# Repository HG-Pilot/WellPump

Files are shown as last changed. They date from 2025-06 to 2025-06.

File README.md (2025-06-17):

# ESP32 - Well Water Pump
An ESP32-powered system designed to automate water well pump control and water tank management, ideal for cabins and cottages or any setup requiring efficient tank filling. Features a user-friendly WiFi web interface for seamless monitoring and control.

## Support This Project

If you find this project helpful and it serves you well, consider showing your appreciation by supporting its development. Your contributions are greatly valued!



## Hardware

- ESP32-S3-DEVKITC-1-N16R8
- Two-Channel Relay Module (High and Low Level Trigger with Dual Optocoupler Isolation)
- I2C Analog-to-Digital Converter (ADS1115) with Current Transformer (CT) for current reading
- Computer ATX Power Supply
- ATX Power Supply Breakout Board
- Cradle for ESP32-S3 Development Boards
- Passive Buzzer Module
- SCT-013 10A 1V AC Current Sensor (Split Core Current Transformer)
- Soil Moisture Sensor (HD-38) for overfill protection
- Temperature Sensor (SHT3X) Water-proof version with 1m cable
- Time-of-Flight (TOF200C) Sensor with VL53L0X for water level measurement
- Submersible 12V ECO-WORTHY Water Pump
- Flexahopper LPT-125 Water Tank
- Additional External NeoPixel RGBW LED on IO Pin 48
- Custom Breakout Board for 3V3 and I2C Lines
- [Hardware List with Pictures](https://github.com/HG-Pilot/WellWaterPump/tree/main/docs/parts).

## Pump Logic

<a href="https://github.com/HG-Pilot/WellWaterPump/blob/main/docs/Pump.Logic.png">
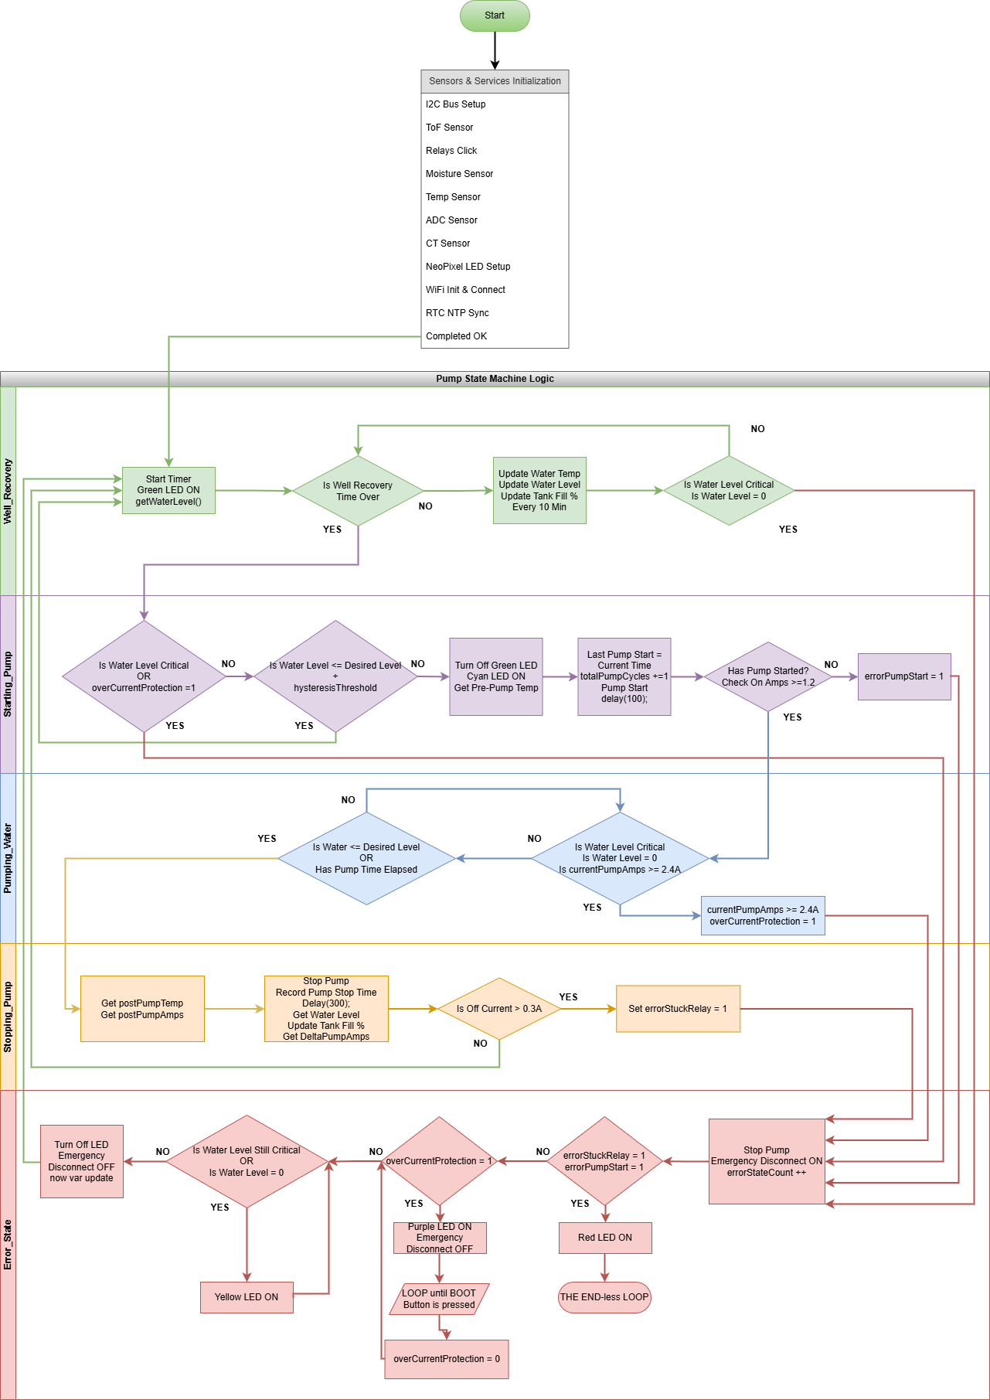
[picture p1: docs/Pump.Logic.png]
Pump Logic
    
</a>
The error logic has since been updated and split into separate **Error States**. Each error condition now has its own dedicated state within the system's state machine for better clarity and manageability. Despite this structural change, the core functionality and error-handling mechanisms remain consistent with the original design.

## Wiring Diagram

The wiring diagram provides a detailed visual guide for setting up the hardware components of the system. Click on the image below to view it in full size.

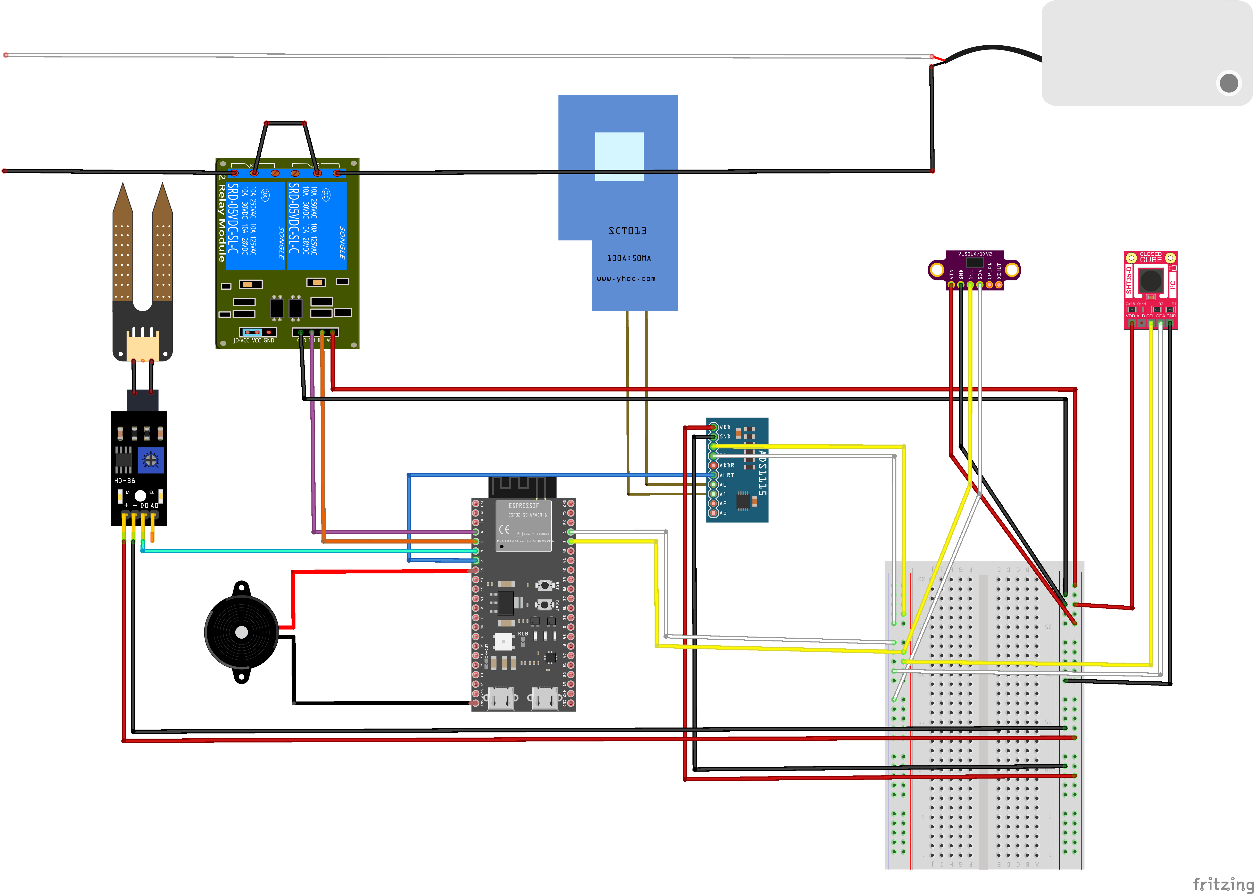
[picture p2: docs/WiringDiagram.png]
Wiring Diagram


## Web Interface

The UI is composed of 4 pages, listed below:

- **HOME**  
  Provides a quick system overview and array of system control buttons.  
  <p align="center">
    <a href="https://github.com/HG-Pilot/WellWaterPump/blob/main/docs/%F0%9F%92%A7ESP32%20Program%20Home%F0%9F%92%A7.png">
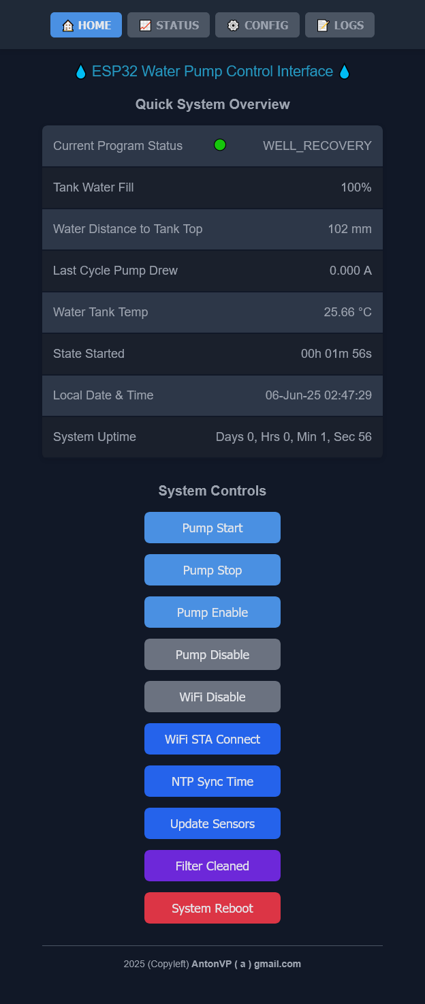
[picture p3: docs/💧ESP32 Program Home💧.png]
HOME Page Screenshot
      
    </a>
  </p>

- **STATUS**  
  Shows live values, system running config, error counters, temperature, and current data.  
  <p align="center">
    <a href="https://github.com/HG-Pilot/WellWaterPump/blob/main/docs/%F0%9F%92%A7ESP32%20Program%20Status%F0%9F%92%A7.png">
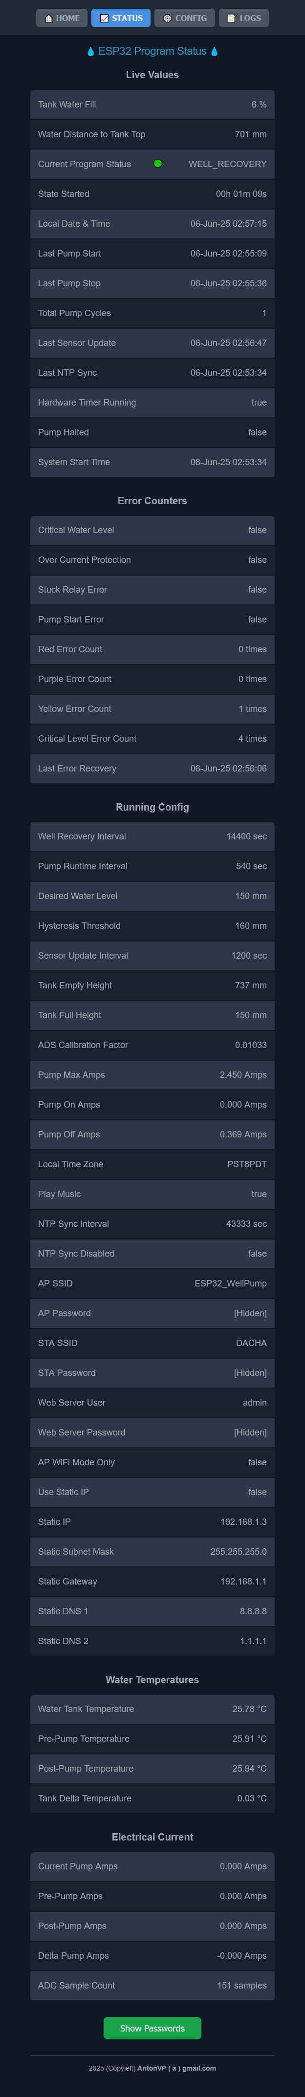
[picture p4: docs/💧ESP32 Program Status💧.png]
STATUS Page Screenshot
      
    </a>
  </p>

- **CONFIG**  
  Provides a system startup configuration interface and factory reset option.  
  <p align="center">
    <a href="https://github.com/HG-Pilot/WellWaterPump/blob/main/docs/%F0%9F%92%A7ESP32%20Program%20Config%F0%9F%92%A7.png">
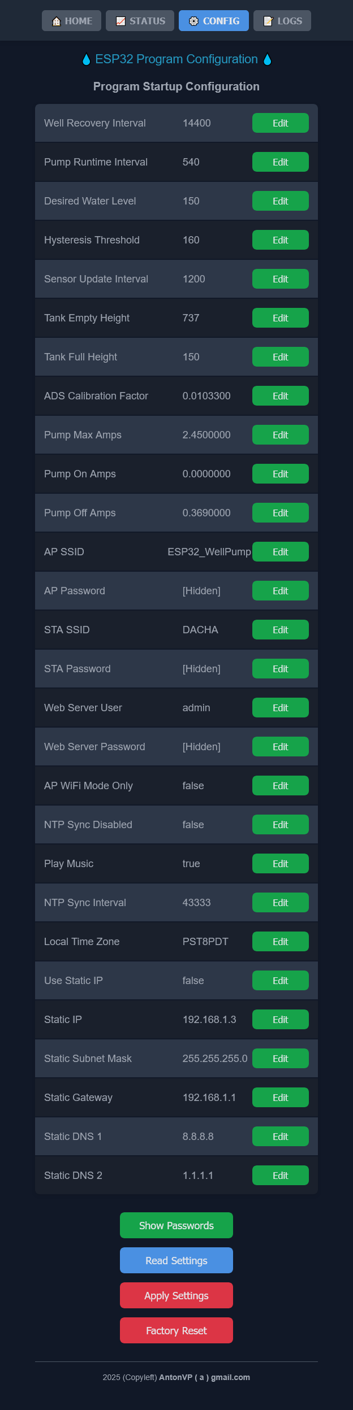
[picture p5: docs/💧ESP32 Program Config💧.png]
CONFIG Page Screenshot
      
    </a>
  </p>

- **LOGS**  
  Displays logs from a 60KB logging circular buffer and allows users to clear and copy the logs.  
  <p align="center">
    <a href="https://github.com/HG-Pilot/WellWaterPump/blob/main/docs/%F0%9F%92%A7ESP32%20Program%20Logs%F0%9F%92%A7.png">
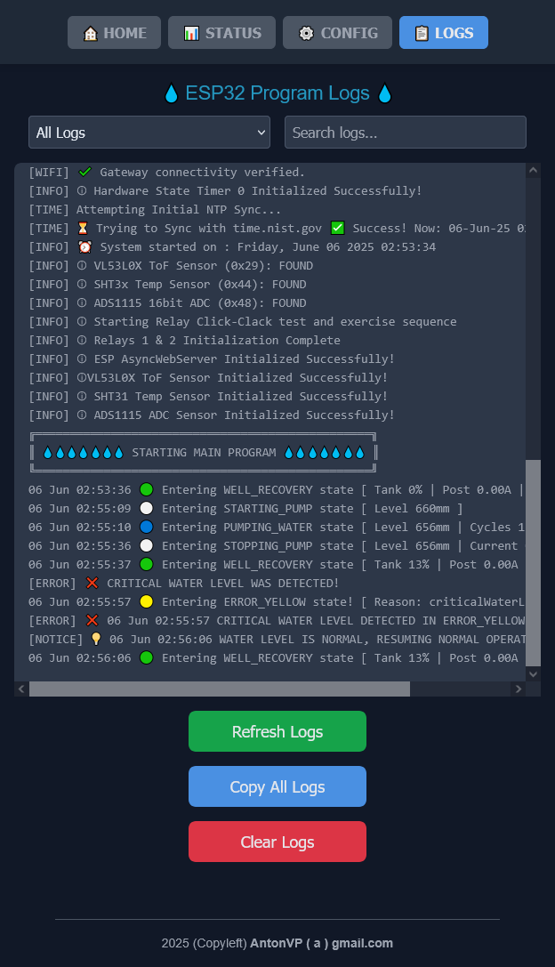
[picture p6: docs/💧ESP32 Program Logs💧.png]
LOGS Page Screenshot
      
    </a>
  </p>

The UI interface supports dark and light modes, optimized for both mobile and desktop versions.

## Program Function and Overview

This program automates the control of a well water pump and water tank filling process using an ESP32 microcontroller.  
It is designed for off-grid cabins, cottages, or any water tank system.  
The software integrates multiple features to ensure efficient operation, user convenience, and system safety:

### Program Features:

- Automated pump control based on tank water levels, well recovery intervals, and timed pumping cycles
- ESP32 hardware timer controls well recovery and pumping intervals
- Well recovery interval allows well water to recover before the next pump cycle begins
- Desired tank water level is configurable; the ToF sensor at the top indicates less distance equals more water
- The ToF sensor takes five consecutive readings, stores them in an array, and calculates the median value after sorting. This approach ensures reliability by tolerating up to two failed reads while providing detailed logs for these occurrences.
- Pump cycles are timed based on your well capacity
- Onboard RGBW LED displays the current operational state of the system
- Logs align with State Machine color states and reflect the same LED colors
- Buzzer, when enabled, provides audible confirmation at the start of each state
- CT coil reads A/C side current draw and can be re-programmed to read DC current using ACS758 or some other Hall effect Current Sensor
- Water temperature is updated at intervals and recorded pre- and post-pump cycle to display the delta water temperature
- Pressing Boot Button exits Pump Disable and Purple Error modes
- System time is derived via NTP and supports time zones and DST
- Approximate tank fill percentage is displayed for semi-circular tanks
- System uptime is calculated and displayed
- Program states and errors feature verbose logging, timestamping, and color coding
- ADS calibration adjusts the CT current value
- The **Update Sensors** button triggers an immediate update and recalculation of temperature, water level, and tank fill percentage.
- Dark and light UI modes ensure optimal readability on mobile and desktop devices

### Safety Features:

- Stuck pump relay detection logic uses a second relay for emergency pump disconnect
- Overfilling is prevented with a critical water level check using a moisture sensor
- In the event of a ToF sensor failure or inability to retrieve a valid reading after two attempts, the system transitions into a **Yellow Error State**, ensuring safety and preventing erroneous operations.
- Over- and under-current pump protection avoids burning out or dry-running the pump
- Hysteresis threshold prevents rapid pump cycling when the tank is nearly full
- System events are logged with a circular buffer, enabling review and troubleshooting

### Connectivity Features:

- Two WiFi modes: STA (if configured) and AP (as a fallback or if STA is disabled)
- Web server on port 80 provides real-time data tracking, program control, and configuration
- NTP time synchronization operates in STA mode when connected to the internet

## Flashing and Compiling

This code can be compiled using Arduino IDE version 2.3.6 or higher, provided all necessary libraries are installed and dependencies are resolved. The external RTTTL library, included in the Data folder, must be installed manually. For the VL53L0X sensor, search for "Pololu VL53L0X" in the Library Manager to add the required library.

For a simpler approach, if you are using an ESP32-S3-DEVKITC-1-N16R8, you can flash pre-compiled firmware directly using the `flash.cmd` script located at [https://github.com/HG-Pilot/WellWaterPump/tree/main/build](https://github.com/HG-Pilot/WellWaterPump/tree/main/build). To proceed, connect your ESP32 to your computer, identify the assigned COM port (you may need to install drivers for the onboard USB-to-UART chip), and execute the `flash.cmd` script. Enter the COM port number in uppercase as prompted, then follow the on-screen instructions to complete the flashing process.

## Acknowledgments

This extensive project wouldn’t have been possible without the incredible support and patience of my wonderful wife.

A heartfelt thank you to her for making this a reality!

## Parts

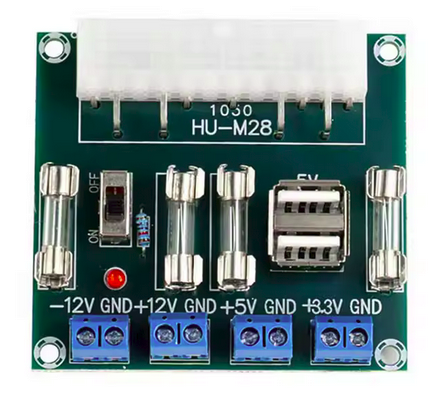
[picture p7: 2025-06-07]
docs/parts/ATX Power Supply Breakout Board.png

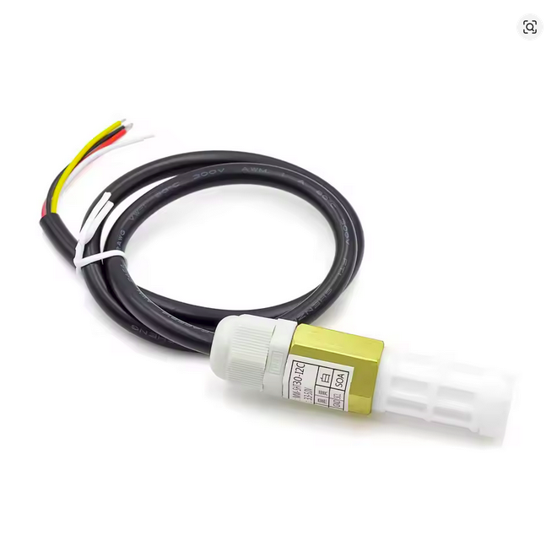
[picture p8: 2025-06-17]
docs/parts/Temp Sensor SHT3X.png

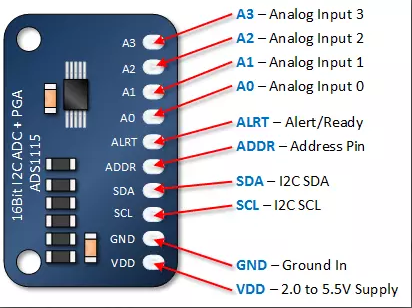
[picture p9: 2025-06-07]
docs/parts/ADS1115 Module ADC.png

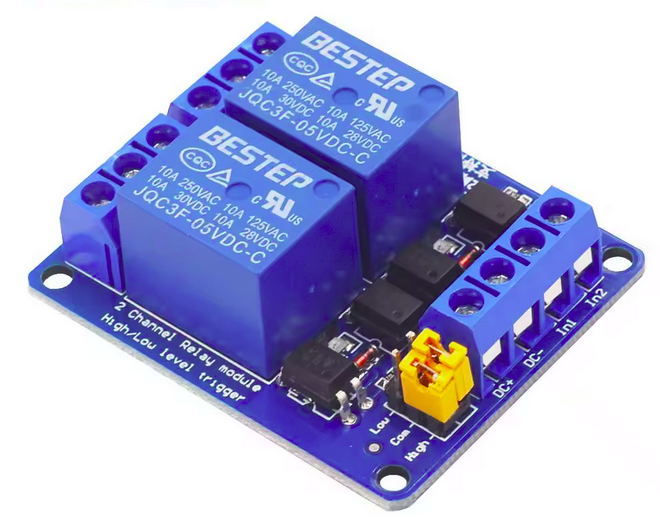
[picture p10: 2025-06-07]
docs/parts/2 Channel Relay Module High and low Level Trigger Dual Optocoupler Isolation Relay Module.png

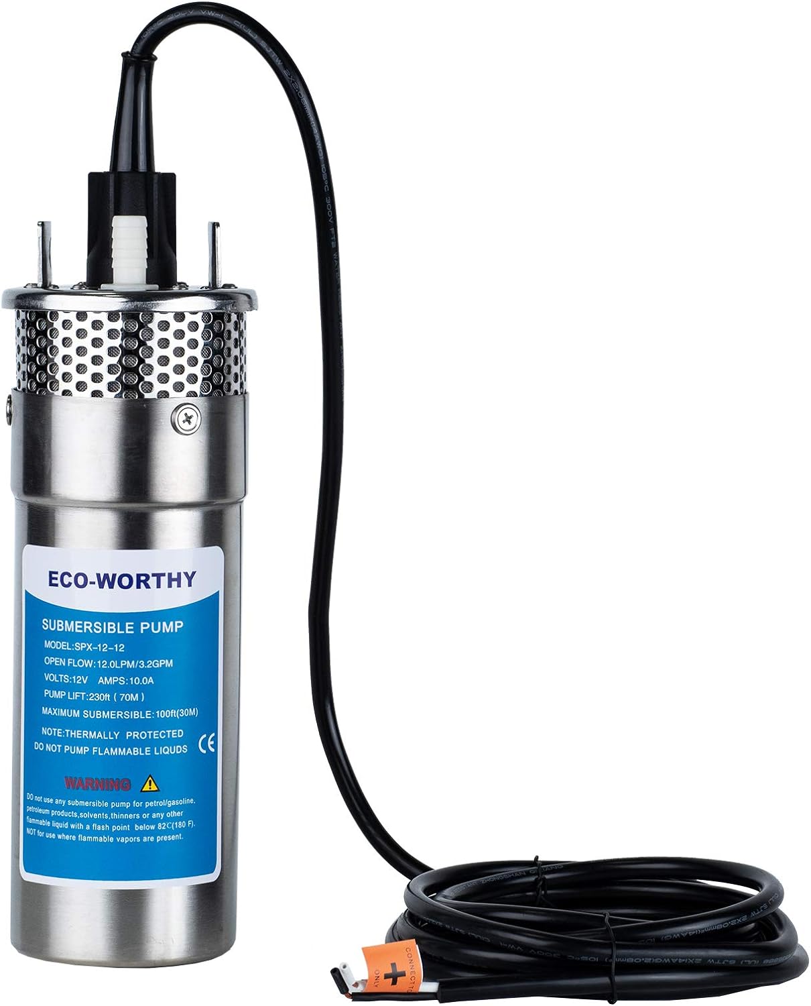
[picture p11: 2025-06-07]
docs/parts/WaterPump.jpg

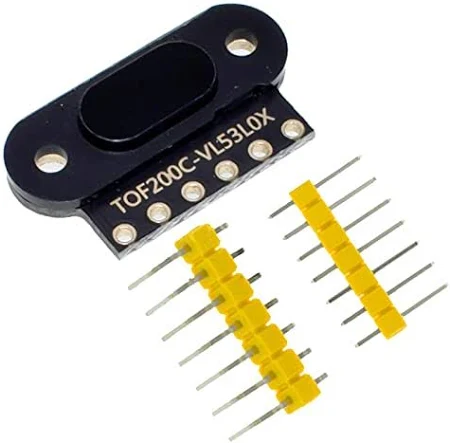
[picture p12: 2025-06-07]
docs/parts/TOF200C Sensor VL53L0X.png

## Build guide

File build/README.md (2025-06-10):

# ESP32 Well Water Pump Release v.1.1
Compiled for ESP32 DevKit1 with 16MB Flash and PSRAM from 2MB to 8MB.
Use flash.cmd file to flash it to your ESP32-S3 MCU.
After flashing configure Start up Config with your desired settings.

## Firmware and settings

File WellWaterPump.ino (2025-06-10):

/**********************************************************************
* 2025 (Copyleft) Anton Polishchuk
* ESP32 Well Water Pump project with Web Interface and WiFi.
* Authtor Contact: 📫 gmail account: antonvp
* DESCRIPTION:
* An ESP32-powered system designed to automate water well pump control
* and water tank management, ideal for cabins and cottages.
* Features a user-friendly WiFi web interface for seamless monitoring and control.
* SETUP:
* Configure your Arduino IDE as per ARDUINO_IDE_CONFIG!.txt before compiling.
* LICENSE:
* This software is licensed under the MIT License.
* Redistribution, modification, or forks must include this banner.
* DISCLAIMER:
* - This software is provided "as is," without warranty of any kind.
* - The author is not responsible for any damages, data loss, or issues
*   arising from its use, under any circumstances.
* - For more information, refer to the full license terms.
**********************************************************************/

// Include Arduino Libraries (RTTTL is external)
#include <Wire.h>
#include <atomic>
#include <RTTTL.h>             // Get Lib here: https://github.com/2ni/ESP32-RTTTL and then import it.
#include <VL53L0X.h>           // Install from Arduino IDE, info: https://github.com/pololu/vl53l0x-arduino
#include <AsyncTCP.h>
#include <ESP32Time.h>
#include "PumpStates.h"
#include <Preferences.h>
#include <ArduinoJson.h>
#include <Adafruit_SHT31.h>
#include <esp32-hal-timer.h>
#include <Adafruit_ADS1X15.h>
#include <ESPAsyncWebServer.h>
#include "Freenove_WS2812_Lib_for_ESP32.h"

// Define the pins and addresses
#define BOOT_BUTTON_PIN 0                  // Get Out of Ampere Jail or HALTED_PUMP state Button, use After Cleaning your Sediment Filter
#define SDA_PIN 1                          // I2C SDA Pin White
#define SCL_PIN 2                          // I2C SCL Pin Yellow Or Green
#define WATER_PUMP_RELAY_PIN 4             // Relay 1 Pin
#define EMERGENCY_PUMP_DISCONNECT_PIN 5    // Relay 2 Pin
#define WATER_CRITICAL_LEVEL_SENSOR_PIN 6  // Moisture sensor DI Pin
#define ADS_ALERT_PIN 7                    // ALERT/RDY Pin ADS1115 Int
#define BUZZER_PIN 15                      // Buzzer connected to GPIO 15
#define NEOPIXEL_PIN 48                    // LED Pin
#define TOF_SENSOR_ADDRESS 0x29            // ToF Laser Sensor Address
#define TEMP_SENSOR_ADDRESS 0x44           // Temp Sensor Address
#define ADS_SENSOR_ADDRESS 0x48            // ADC+PGA Sensor Address

// Declare global state variable
PumpState currentState = static_cast<PumpState>(-1);  // Invalid initial value

// Time Variables
const char* ntpServers[] = { "time.nist.gov", "time.epl.ca", "pool.ntp.org" };
String localTimeZone = "PST8PDT";
uint32_t ntpSyncInterval = 43333;  // ~12 hours in seconds
int64_t stateStartTime = 0;
int64_t lastSensorUpdate = 0;
int64_t ntpLastSyncTime = 0;
int64_t ntpNewTime = 0;
int64_t systemStartTime = 0;
volatile int64_t now = 0;
bool ntpSyncDisabled = false;
std::atomic<time_t> stateRemainingSeconds(0);  // Tracks timer countdown
hw_timer_t* stateCountdownTimer = NULL;        // GPTimer handle
bool isHwTimer0Running = false;                // Track Hardware Timer 0 State

// Global Variables for Water Level Control
uint32_t wellRecoveryInterval = 14400; // in seconds
uint32_t pumpRuntimeInterval = 540;    // in seconds
uint16_t desiredWaterLevel = 150;      // Pump water to this target level
uint16_t hysteresisThreshold = 160;    // Pump Hysteresis Vlaue
uint16_t currentWaterLevel = 1;        // Distance from ToF Sensor to Water Level in mm
uint32_t sensorUpdateInterval = 1200;  // in seconds
uint16_t tankFillPercentage = 0;       // Updated by getWaterPercentage()
uint16_t tankEmptyHeight = 737;        // 0% level (mm)
uint16_t tankFullHeight = 150;         // 100% level (mm)
uint32_t totalPumpCycles = 0;
int64_t lastPumpStart = 0;  // Last time Pump started
int64_t lastPumpStop = 0;   // Last time Pump stopped
bool pumpIsHalted = false;  // Disables Pump
bool playMusic = true;      // Music enabled by default

// Error counters & Variables
volatile bool criticalWaterLevel = false;     // Variable Updated directly by ISR, stores if water level is normal or critical 
volatile bool overCurrentProtection = false;  //Reset to 0 by Boot Button, Leads to Purple error state.
volatile bool errorStuckRelay = false;        //Reboot to clear, Leads to Red error state, Check Relay 1 if true.
uint16_t errorPumpStart = 0;
uint16_t errorRedCount = 0;
uint16_t errorPurpleCount = 0;
uint16_t errorYellowCount = 0;
uint32_t errorCriticalLvlCount = 0;
int64_t errorLastRecovery = 0;

// Global Temperature variables
float waterTankTemp = 0.0F;
float prePumpTemp = 0.0F;
float postPumpTemp = 0.0F;
float tankDeltaTemp = 0.0F;

// Global Current (Amps) variables
float currentPumpAmps = 0.0F;  // getPumpCurrent() updates this Var
float prePumpAmps = 0.0F;
float postPumpAmps = 0.0F;
float deltaPumpAmps = 0.0F;
float pumpMaxAmps = 2.45F;  // Value from Pref
float pumpOnAmps = 1.11F;   // Value from Pref 1.2
float pumpOffAmps = 0.36F;  // Value from Pref 0.3

// ADS Constants & Vars
const float multiplier = 0.0625F;       // ADS1115 default multiplier for GAIN_TWO 0.0625F
float adsCalibrationFactor = 0.01033F;  // Use for calibration of your ADS1115 ADC
uint16_t adcSampleCount = 0;            // Tracks ADS voltage samples per Window
volatile bool adsDataReady = false;     // ADS & ISR Data Readiness Flag

// WiFi SSIDs & Passwords
String apSSID = "ESP32_WellPump";
String apPass = "12345678";
String staSSID = "YourSSID";
String staPass = "12345678";

// Static IP Configuration (STA Mode)
IPAddress staStaticIP(192, 168, 1, 3);
IPAddress staStaticSM(255, 255, 255, 0);
IPAddress staStaticGW(192, 168, 1, 1);
IPAddress staStaticDN1(8, 8, 8, 8);
IPAddress staStaticDN2(1, 1, 1, 1);
bool useStaStaticIP = false;              // Enable Static IP in STA WiFi Mode
bool apWifiModeOnly = false;              // Use AP WiFi Mode only and don't try to re-connect to STA SSID

// WebServer Login credentials
String webServerUser = "admin";
String webServerPass = "WellPump";

// Forward Declarations, these live in Web.ino & WiFi.ino
extern void initWebServer();
extern void startWiFi();
extern void handleWiFi();

// PSRAM Log Buffer Vars & Functions
const size_t LOG_BUFFER_SIZE = 61440; // 60KB !!! It will crash at 64KB so stay below it !!! To go above 64KB you would need to chunk the JSON logs to ~48KB and reasemble at the client side, no time to do this :-(
char* volatile psramLogBuffer = nullptr;
volatile size_t logHead = 0;
volatile size_t logTail = 0;

class PSRAMLogger : public Print {
private:
  static const size_t SRAM_BUFFER_SIZE = 128; // Small SRAM intermediate buffer for chunking
  char sramBuffer[SRAM_BUFFER_SIZE]; // SRAM buffer array
  size_t sramIndex = 0; // Tracks SRAM buffer position
public:
  PSRAMLogger() { // Initialize SRAM buffer
    memset(sramBuffer, 0, SRAM_BUFFER_SIZE);
  }
  size_t write(uint8_t c) override {
    // Store in SRAM buffer
    if (psramLogBuffer) {
      sramBuffer[sramIndex++] = c; // Store in SRAM buffer
      if (c == '\n' || sramIndex >= SRAM_BUFFER_SIZE) { // Changed: Commit on \n or full
        noInterrupts(); // Protect only PSRAM commit
        for (size_t i = 0; i < sramIndex; i++) {
          psramLogBuffer[logHead] = sramBuffer[i];
          logHead = (logHead + 1) % LOG_BUFFER_SIZE;
          if (logHead == logTail) logTail = (logTail + 1) % LOG_BUFFER_SIZE;
        }
        interrupts();
        sramIndex = 0; // Reset SRAM buffer index
      }
    }
    // Always mirror to Serial
    return Serial.write(c);
  }
};

// Global instance
PSRAMLogger logSerial;

void setupLogger() {
  Serial.begin(115200); // Initialize real Serial first
  if (!psramInit()) {   // Initialize PSRAM
    Serial.println("[ERROR] ❌ PSRAM Init Failed");
    return;
  }
  if (!psramFound()) {
    Serial.println("[ERROR] ❌ PSRAM Was Not Found");
    return;
  }
  psramLogBuffer = (char*)ps_malloc(LOG_BUFFER_SIZE);
  if (!psramLogBuffer) { // Check ps_malloc failure
    Serial.println("[ERROR] ❌ PSRAM allocation failed for Log Buffer");
    return;
  }
  Serial.println("[INFO] ⓘ PSRAM Logger Initialized Successfully!, 480KB Allocated");
}

String getLogsForWeb() {
  if (!psramLogBuffer) return "PSRAM Logging Not Available";
  
  if (logHead >= LOG_BUFFER_SIZE || logTail >= LOG_BUFFER_SIZE) return "Invalid buffer indices";

  noInterrupts();
  size_t currentTail = logTail;
  size_t currentHead = logHead;
  interrupts();

  if (currentHead == currentTail) return "No Logs Available";

  if (currentHead >= LOG_BUFFER_SIZE || currentTail >= LOG_BUFFER_SIZE) return "Invalid Buffer Indices";

  // Create a temporary non-volatile buffer
  size_t available = (currentHead >= currentTail) ? 
    (currentHead - currentTail) : 
    (LOG_BUFFER_SIZE - currentTail + currentHead);
    logSerial.printf("[INFO] ⓘ Sending %u bytes of Logs to Web, Free Heap: %lu, Free PSRAM: %lu\n", available, ESP.getFreeHeap(), ESP.getFreePsram());
  if (!psramFound()) return "PSRAM Not Initialized";
  char* tempBuffer = (char*)ps_malloc(available + 1);
  if (!tempBuffer) return "PSRAM Log Buffer Memory Error";

  // Copy from volatile to temporary buffer
  if (currentHead > currentTail) {
    memcpy(tempBuffer, (const void*)(psramLogBuffer + currentTail), available);
  } else {
    size_t firstChunk = LOG_BUFFER_SIZE - currentTail;
    memcpy(tempBuffer, (const void*)(psramLogBuffer + currentTail), firstChunk);
    memcpy(tempBuffer + firstChunk, (const void*)psramLogBuffer, currentHead);
  }

  tempBuffer[available] = '\0';
  String result(tempBuffer);
  free(tempBuffer);
  
  return result;
}

// Web server object
AsyncWebServer server(80);

// Declaring the RTC object
ESP32Time rtc;

// Declaring ToF_Sensor object
VL53L0X ToF_Sensor;

// Declaring Temp_Sensor object
Adafruit_SHT31 sht31;

// Declaring ADS_Sensor object
Adafruit_ADS1115 ads;

// Global RTTTL object
RTTTL rtttl(BUZZER_PIN); // Default LEDC channel 0

// Declaring LED strip
Freenove_ESP32_WS2812 strip(1, NEOPIXEL_PIN, 0, TYPE_GRB);

//Setting up an ISR to update a Variable when Pin6 goes Low. Choose from Two Options Compatibility vs speed, second is faster.
// void IRAM_ATTR criticalWaterLevelISR() { criticalWaterLevel = (digitalRead(WATER_CRITICAL_LEVEL_SENSOR_PIN) == LOW);}
void IRAM_ATTR criticalWaterLevelISR() {
  criticalWaterLevel = !(REG_READ(GPIO_IN_REG) & (1 << WATER_CRITICAL_LEVEL_SENSOR_PIN));
  errorCriticalLvlCount++;
}

// ISR for ADS ALERT/RDY Pin to Set flag when data is ready
void IRAM_ATTR adsDataReadyISR() {
  adsDataReady = true;
}

// ISR for Well Recovery & Pump Timers
void IRAM_ATTR onTimer() {
  time_t current = stateRemainingSeconds.load();  // Atomic read
  if (current > 0) {
    stateRemainingSeconds.store(current - 1);  // Atomic write
  }
}

// RTTTL melodies for each state
const char* WellRecovery = "SMBtheme:d=4,o=5,b=100:8p,8c6,16p,8g,16p,8e,16p,8a,8b,16a#,8a,16g.,16e6,16g6,8a6,16f6,8g6,8e6,16c6,16d6,8b,16p";
const char* PumpingWater = "DasBoot:d=4,o=5,b=100:d#.4,8d4,8c4,8d4,8d#4,8g4,a#.4,8a4,8g4,8a4,8a#4,8d,2f.,p";
const char* ErrorRed = "StarWars:d=4,o=5,b=112:8d.,16p,8d.,16p,8d.,16p,8a#4,16p,16f,8d.,16p,8a#4,16p,16f,d.,8p,8a.,16p,8a.,16p,8a.,16p,8a#,16p,16f,8c#.,16p,8a#4,16p,16f,d.,8p";
const char* ErrorPurple = "Impossible:d=16,o=5,b=100:32d,32d#,32e,32f,32f#,32g,g,8p,g,8p,a#,p,c6,p,g,8p,g,8p,f,p,f#,p,g,8p,g,8p,a#,p,c6,p,g,8p,g,8p,f,p,f#,p,a#,g,2d,32p,a#,g,2c#,32p,a#,g,2c,p,a#4,c";
const char* ErrorYellow = "Toccata:d=4,o=5,b=160:16a4,16g4,1a4,16g4,16f4,16d4,16e4,2c#4,16p,d.4,2p,16a4,16g4,1a4,8e.4,8f.4,8c#.4,2d4";
const char* HaltedPump = "SMBunderground:d=16,o=6,b=100:c,c5,a5,a,a#5,a#,2p,8p,c,c5,a5,a,a#5,a#,2p,8p,f5,f,d5,d,d#5,d#,2p,8p,f5,f,d5,d,d#5,d#,2p,32d#,d,32c#,c,p,d#,p,d,p,g#5,p,g5,p,c#,p,32c,f#,32f,32e,a#,32a,g#,32p,d#,b5,32p,a#5,32p,a5,g#5";
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
void loop() {

  // Pereodic NTP Sync
  ntpPeriodicSync();
  yield();

  // Update playback (non-blocking)
  rtttl.play();
  yield();

  // Update WiFi State Machine
  handleWiFi();
  yield();

  static int64_t lastCurrentCheck = 0;
  static int64_t lastLevelCheck = 0;
  static bool criticalMessagePrinted = false;
  
  now = rtc.getEpoch();
  yield();


  switch (currentState) {
    case WELL_RECOVERY:
      strip.setLedColorData(0, 0x008000);
      strip.show();  // Green

      if (criticalWaterLevel == true || currentWaterLevel == 0) {
        currentState = ERROR_YELLOW;
        logSerial.printf("[ERROR] ❌ %s!\n", criticalWaterLevel ? "CRITICAL WATER LEVEL WAS DETECTED" : "TOF SENSOR RANGING FAILURE AFTER 15 ATTEMPTS");
        stateStartTime = now;
        errorYellowCount++;
        stopStateTimer();
        logStateTransition(currentState);
        break;
      }

      if (stateRemainingSeconds.load() == 0) {  // Atomic read
        currentState = STARTING_PUMP;
        stateStartTime = now;
        stopStateTimer();
        logStateTransition(currentState);
      } else {
        getSensorsUpdated();
      }
      break;

    case STARTING_PUMP:

      strip.setLedColorData(0, 0x808080);
      strip.show();  // White
      if (criticalWaterLevel == true || overCurrentProtection == true) {
        if (overCurrentProtection == true) {
          currentState = ERROR_PURPLE;
          logSerial.println("[ERROR] ❌ OVER CURRENT PROTECTION TRIGGERED DURING PUMP STARTUP!");
          stateStartTime = now;
          errorPurpleCount++;
        } else if (criticalWaterLevel == true) {
          currentState = ERROR_YELLOW;
          logSerial.println("[ERROR] ❌ CRITICAL WATER LEVEL DETECTED DURING PUMP STARTUP!");
          stateStartTime = now;
          errorYellowCount++;
        }
        stopStateTimer();
        logStateTransition(currentState);
        break;
      }

      getWaterLevel();
      if (currentWaterLevel <= desiredWaterLevel + hysteresisThreshold) {
        currentState = WELL_RECOVERY;
        stateStartTime = now;
        startStateTimer(wellRecoveryInterval);
        logStateTransition(currentState);
      } else {
        getWaterTemp("pre");
        digitalWrite(WATER_PUMP_RELAY_PIN, HIGH);
        startStateTimer(pumpRuntimeInterval);
        lastPumpStart = now;
        totalPumpCycles++;
        yield();

        if (getPumpCurrent() >= pumpOnAmps) {
          prePumpAmps = currentPumpAmps;
          currentState = PUMPING_WATER;
          stateStartTime = now;
          logStateTransition(currentState);
        } else {
          errorPumpStart++;
          currentState = ERROR_RED;
          logSerial.println("[FATAL] 🔴 CURRENT WASN'T DETECTED AFTER PUMP STARTUP, PROGRAM HALTED!");
          stateStartTime = now;
          errorRedCount++;
          stopStateTimer();
          logStateTransition(currentState);
        }
      }
      break;

    case PUMPING_WATER:

      strip.setLedColorData(0, 0x0080FF);
      strip.show();  // Cyan
      if (criticalWaterLevel == true || currentWaterLevel == 0) {
        currentState = ERROR_YELLOW;
        logSerial.printf("[ERROR] ❌ %s!\n", criticalWaterLevel ? "CRITICAL WATER LEVEL WAS DETECTED" : "TOF SENSOR RANGING FAILURE AFTER 15 ATTEMPTS");
        stateStartTime = now;
        errorYellowCount++;
        stopStateTimer();
        logStateTransition(currentState);
        break;
      }

      // Check current every 600ms (non-blocking)
      if (millis() - lastCurrentCheck >= 600) {
        getPumpCurrent();  // Blocking I/O, but throttled
        yield();
        lastCurrentCheck = millis();

        yield();
        if (currentPumpAmps >= pumpMaxAmps) {
          overCurrentProtection = true;
          currentState = ERROR_PURPLE;
          logSerial.println("[ERROR] ❌ OVERCURRENT CONDITION DETECTED DURING PUMPING, CLEAN FILTER OR CHECK PUMP!");
          logSerial.println("[ALERT] 🚨 ONCE FILTER IS CLEANED PRESS BOOT BUTTON TO RESUME THE PROGRAM!");
          stateStartTime = now;
          errorPurpleCount++;
          stopStateTimer();
          logStateTransition(currentState);
          break;
        }
      }

      if (millis() - lastLevelCheck >= 1000) {
        getWaterLevel();  // Blocking I/O, but throttled
        lastLevelCheck = millis();
        yield();

        if ((currentWaterLevel > 0 && currentWaterLevel <= desiredWaterLevel) || (stateRemainingSeconds.load() == 0)) {  // Atomic read
          currentState = STOPPING_PUMP;
          stateStartTime = now;
          stopStateTimer();
          logStateTransition(currentState);
        }
      }
      break;

    case STOPPING_PUMP:

      strip.setLedColorData(0, 0x808080);
      strip.show();  // White
      getWaterTemp("post");
      yield();
      postPumpAmps = getPumpCurrent();
      digitalWrite(WATER_PUMP_RELAY_PIN, LOW);
      lastPumpStop = now;
      yield();
      deltaPumpAmps = postPumpAmps - prePumpAmps;
      getWaterLevel();
      yield();
      getWaterPercentage();

      if (getPumpCurrent() > pumpOffAmps) {
        currentState = ERROR_RED;
        logSerial.println("[FATAL] 🔴 STUCK RELAY #1 CONDITION DETECTED, CHECK RELAY 1, PROGRAM HALTED!");
        errorStuckRelay = 1;
        errorRedCount++;
        stateStartTime = now;
        stopStateTimer();
        logStateTransition(currentState);
        yield();
      } else {
        currentState = WELL_RECOVERY;
        stateStartTime = now;
        startStateTimer(wellRecoveryInterval);
        logStateTransition(currentState);
        yield();
      }
      break;

    case ERROR_RED:
      strip.setLedColorData(0, 0x800000);
      strip.show();  // Red
      digitalWrite(WATER_PUMP_RELAY_PIN, LOW);

      if (errorStuckRelay == true) {
        digitalWrite(EMERGENCY_PUMP_DISCONNECT_PIN, HIGH);
      } else if (errorPumpStart == 1) {
        if (criticalWaterLevel) {
          digitalWrite(EMERGENCY_PUMP_DISCONNECT_PIN, HIGH);
          if (!criticalMessagePrinted) {
            logSerial.printf("[ERROR] ❌ %s CRITICAL WATER LEVEL DETECTED IN ERROR_RED STATE!\n", rtc.getTime("%d %b %H:%M:%S").c_str());
            criticalMessagePrinted = true;
          }
        } else {
          digitalWrite(EMERGENCY_PUMP_DISCONNECT_PIN, LOW);
          criticalMessagePrinted = false;
        }
      }
      getSensorsUpdated();
      break;

    case ERROR_PURPLE:
      strip.setLedColorData(0, 0x8000FF);
      strip.show();  // Purple
      digitalWrite(WATER_PUMP_RELAY_PIN, LOW);

      if (!criticalWaterLevel) {
        digitalWrite(EMERGENCY_PUMP_DISCONNECT_PIN, LOW);
      }
      if (criticalWaterLevel) {
        if (!criticalMessagePrinted) {
          logSerial.printf("[ERROR] ❌ %s CRITICAL WATER LEVEL DETECTED IN ERROR_PURPLE STATE!\n", rtc.getTime("%d %b %H:%M:%S").c_str());
          criticalMessagePrinted = true;
        }
        digitalWrite(EMERGENCY_PUMP_DISCONNECT_PIN, HIGH);
      } else {
        criticalMessagePrinted = false;
        digitalWrite(EMERGENCY_PUMP_DISCONNECT_PIN, LOW);
      }
      if (digitalRead(BOOT_BUTTON_PIN) == LOW) {
        overCurrentProtection = false;
        currentState = WELL_RECOVERY;
        logSerial.printf("[NOTICE] 💡 %s BOOT BUTTON WAS PRESSED, RESUMING NORMAL OPERATION!\n", rtc.getTime("%d %b %H:%M:%S").c_str());
        errorLastRecovery = now;
        stateStartTime = now;
        startStateTimer(wellRecoveryInterval);
        logStateTransition(currentState);
      }
      getSensorsUpdated();
      break;

    case ERROR_YELLOW:
      strip.setLedColorData(0, 0x808000);
      strip.show();  // Yellow
      digitalWrite(WATER_PUMP_RELAY_PIN, LOW);
      lastLevelCheck = 0;

      if (criticalWaterLevel) {
        if (!criticalMessagePrinted) {
          logSerial.printf("[ERROR] ❌ %s CRITICAL WATER LEVEL DETECTED IN ERROR_YELLOW STATE!\n", rtc.getTime("%d %b %H:%M:%S").c_str());
          criticalMessagePrinted = true;
        }
        digitalWrite(EMERGENCY_PUMP_DISCONNECT_PIN, HIGH);
      } else {
        criticalMessagePrinted = false;
        digitalWrite(EMERGENCY_PUMP_DISCONNECT_PIN, LOW);
      }
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

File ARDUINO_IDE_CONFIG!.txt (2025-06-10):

Setup your board in Arduino IDE Tools menu, it should looks something like this:

Board: “ESP32S3 Dev Module”
USB CDC On Boot: “Enabled”
CPU Frequency: “240MHZ (WiFi)”
Core Debug Level: “None”
USB DFU On Boot: “Disabled”
Erase All Flash Before Sketch Upload: “Enabled” (For the first compile, After first boot you can set it to disable, Factory Reset has the same effect)
Events Run On: “Core 1”
Flash Mode: “QIO 80MHz”
Flash Size: “16MB (128Mb)”
JTAG Adapter: “Integrated USB JTAG”
Arduino Runs On: “Core 1”
USB Firmware MSC On Boot: “Disabled”
Partition Scheme: “16M Flash (3MB APP/9.9MB FATFS)”
PSRAM: “OPI PSRAM”
Upload Mode: “UARTO / Hardware CDC”
Upload Speed: “115200”
USB Mode: “Hardware CDC and JTAG”
Zigbee Mode: “Disabled”
Programmer: “Esptool”

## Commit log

2025-06-06 Update 💧ESP32 Program Config💧.png
2025-06-06 Doc Update
    [WiringDiagram.fzz]
2025-06-10 Added ARDUINO_IDE_CONFIG!.txt
    v.1.1 Release
    [ARDUINO_IDE_CONFIG!.txt]
2025-06-17 Waterproof Sensor
